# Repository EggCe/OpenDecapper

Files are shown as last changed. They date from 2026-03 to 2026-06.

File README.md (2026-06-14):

# OpenDecapper




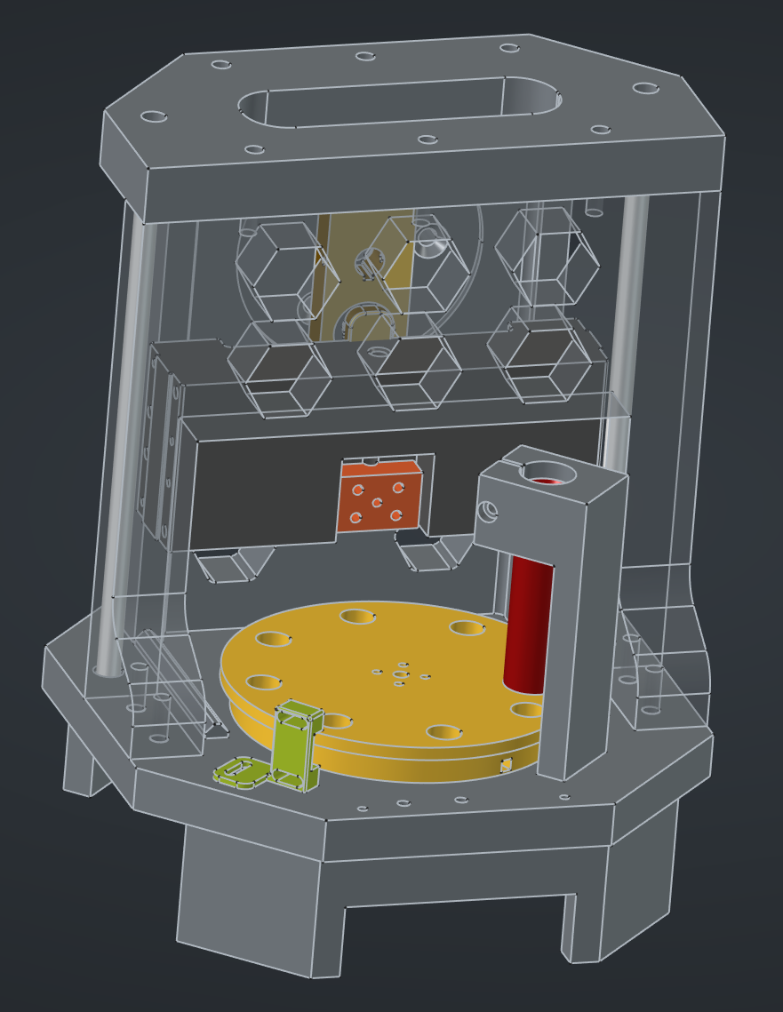
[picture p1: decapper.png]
OpenDecapper Machine


**OpenDecapper** is an open-source, automated hardware solution for decapping fired brass. This project aims to provide a reliable, high-speed alternative to manual decapping by leveraging 3D-printed mechanics and Arduino-based control.

This is a DIY project for educational purposes. Users are responsible for ensuring compliance with local laws and intellectual property.
---

## 📂 Repository Structure

* **/code**: Source code (`.ino`) for the microcontroller. Handles motor control, cycle timing, and sensor feedback.
* **/stl**: STL files for all structural and functional components.

---

## 🛠 Features

* **Automated Cycling:** Continuous feeding and de-priming.
* **Open Hardware:** Fully customizable to fit different bench setups.
* **Adjustable Speed:** Code-based control for different brass conditions.
* **Modular Toolheads:** Quick-swap heads for different calibers.

[Video](https://youtube.com/shorts/UAMVNMfc45k?feature=share)

---

## 🖨️ Print Instructions

For maximum durability and mechanical precision, use the following settings:

- **Baseplate / Frame / Motor-Mount / Decapping-Frame:**

| Setting | Value |
| :--- | :--- |
| **Material** | PETG |
| **Infill** | 40% adaptive cubic |
| **Walls** | 8 |
| **Top Layers** | 7 |
| **Bottom Layers** | 7 |

- **Pleuel/Excenter:**

| Setting | Value |
| :--- | :--- |
| **Material** | PLA |
| **Infill** | 70% Gyroid |
| **Walls** | 8 |
| **Top Layers** | 7 |
| **Bottom Layers** | 7 |

- **Everything Else**

| Setting | Value |
| :--- | :--- |
| **Material** | PLA or PETG |
| **Infill** | 20% Gyroid |
| **Walls** | 3 |
| **Top Layers** | 3 |
| **Bottom Layers** | 3 |

---

## 🚀 Getting Started

### 1. Hardware Requirements
* **Electronics:** Arduino (Nano/Uno), NEMA 17 Stepper Motor, Stepper Driver (TMC2209 or TMC2208).
* **Tools:** 3D Printer (PETG recommended), M3/M5 Bolt kit, 8mm Linear Rails.

### 2. Software Setup
1.  Clone this repository:
    ```bash
    git clone [https://github.com/EggCe/OpenDecapper.git](https://github.com/EggCe/OpenDecapper.git)
    ```
2.  Open `/code/sketch/sketch.ino` in the Arduino IDE.
3.  Install necessary libraries (e.g., `AccelStepper`).
4.  Upload to your board.

---

## 📅 Upcoming Milestones

- [ ] **Comprehensive BOM:** Detailed list of all off-the-shelf parts and fasteners.
- [ ] **Assembly Manual:** Step-by-step instructions with wiring diagrams.
- [ ] **Calibration Guide:** Tips for timing the stroke and sensor alignment.

---

## 🤝 Contributing

Contributions are what make the open-source community such an amazing place to learn, inspire, and create.

---

## ⚖️ License

This project is licensed under the **Creative Commons Attribution-NonCommercial 4.0 International (CC BY-NC 4.0)**. 

**Summary:** You are free to share and adapt this material for non-commercial purposes only. If you remix or build upon this work, you must give appropriate credit. Commercial use of these designs or code is prohibited without explicit permission.

---

**⚠️ SAFETY WARNING:** — READ BEFORE BUILDING OR OPERATING

This machine will crush fingers and hands without breaking a sweat. It is a motorized press driven by a DC motor with significant torque. It does not know or care if something is in the way.

* NEVER run this machine unattended.
* NEVER allow children near the machine, whether it is running or not.
* Keep your hands and fingers away from the machine at ALL times when it is powered on.
* Treat it like any industrial press — it can and will cause serious injury if misused.

LIABILITY DISCLAIMER: This project is provided as-is with absolutely no warranty of any kind. The author(s) accept no responsibility or liability for any injury, damage, or loss resulting from building, modifying, or operating this machine. You build and use it entirely at your own risk.

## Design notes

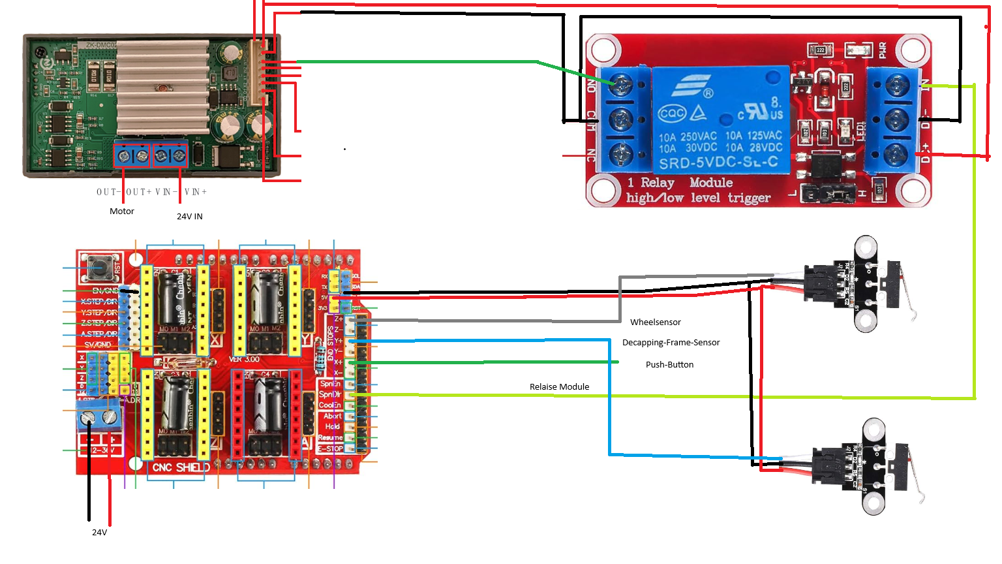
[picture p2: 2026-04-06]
electronics.png

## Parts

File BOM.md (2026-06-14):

# Bill of Materials (BOM) - Project OpenDecapper

### Electronics
| Item | Description | Quantity | Link |
| :--- | :--- | :--- | :---: |
| **Power Supply** | 24V 3A DC Power Supply | 1 | https://de.aliexpress.com/item/33051556213.html |
| **DC Motor** | 24V DC Motor (220 RPM) | 1 | https://de.aliexpress.com/item/1005009774429443.html |
| **DC Motor Controller** | ZK-DMC02 Motor Controller | 1 | https://www.amazon.de/dp/B0GKXSY5CK |
| **Microcontroller** | Arduino Uno R3 | 1 | https://de.aliexpress.com/item/1005007040646073.html |
| **Expansion Board** | CNC Shield V3 | 1 | https://de.aliexpress.com/item/1005007040646073.html |
| **Stepper Driver** | TMC2209 or TMC2208 Stepper Driver | 1 | https://de.aliexpress.com/item/1005006323811276.html |
| **Stepper Motor** | NEMA 17 (1.5A) | 1 | https://de.aliexpress.com/item/1005008383555860.html |
| **Limit Switche** | Mechanical Endstop Limit Switch | 1 | https://de.aliexpress.com/item/32816845922.html |
| **IR Limit Switche** | Infrared Limit Switch | 1 | https://de.aliexpress.com/item/1005006947924085.html |
| **Push-Button** | 12mm Momentary Switch | 1 | https://de.aliexpress.com/item/4000266966662.html |
| **Relais** | Single Channel Relais Modul 5V | 1 | https://de.aliexpress.com/item/1005005319972049.html |

### Mechanical & Motion
| Item | Description | Quantity | Link |
| :--- | :--- | :--- | :---: |
| **Coupling** | 5mm ID Flange Shaft Coupling | 1 | https://de.aliexpress.com/item/1005011579618575.html |
| **Linear Rods** | 8mm Diameter, 215 mm Length | 2 | https://de.aliexpress.com/item/1005009454387776.html | 
| **Linear Bearings** | SC8UU (Gleitlager) | 4 | https://de.aliexpress.com/item/4000861690916.html |
| **Radial Bearing** | 6801 Bearing 12mm ID, 21mm OD| 2 | https://de.aliexpress.com/item/1005006035063081.html |
| **Decapping Pin** | Lee Small Pistol Decapping Pin | 1 |
| **Dillon Index Ball** | Dillon 13891_375 INDEX_BALL (or any 12mm Ball) | 1 |
| **Dillon Index Ball Spring** | Dillon 13997_INDEX BALL SPRING (or any spring fitting) | 1 |

### Hardware (Screws)
| Type | Size | Quantity |
| :--- | :--- | :---: |
| **M6 Bolt** | M6 * 25mm | 14 |
| **M5 Countersunk Bolt** | M6 * 20mm | 3 |
| **M3 Bolt** | M3 * 12mm | 12 |
| **M3 Bolt** | M3 * 8mm | 12 |
| **M3 Bolt** | M3 * 25mm | 30 |
| **M3 Bolt** | M3 * 30mm | 20 |

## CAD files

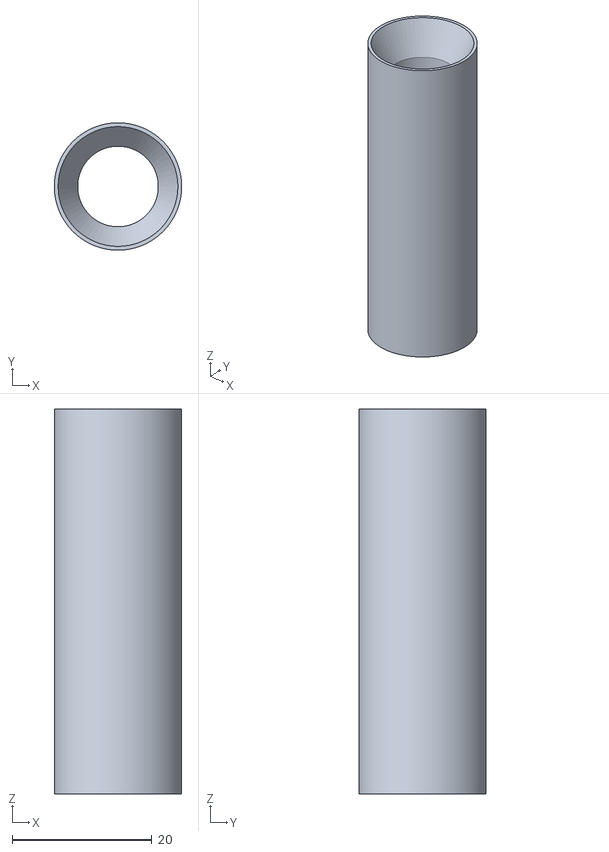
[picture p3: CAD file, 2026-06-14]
stl/caliberConversion/feed-tube-357.stl
18.2 x 18.2 x 55.0

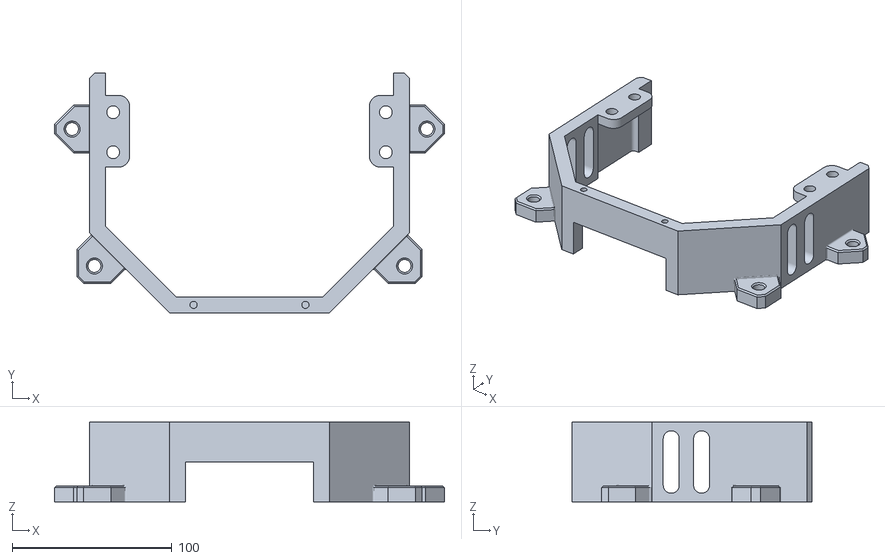
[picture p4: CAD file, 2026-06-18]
stl/FeetExtended-Körper.stl
244.0 x 150.0 x 50.0

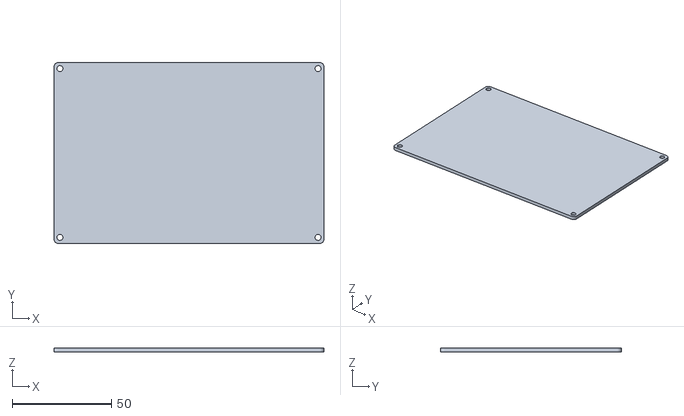
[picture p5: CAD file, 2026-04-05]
stl/pcb/electronics-lid.stl
136.0 x 91.0 x 2.00

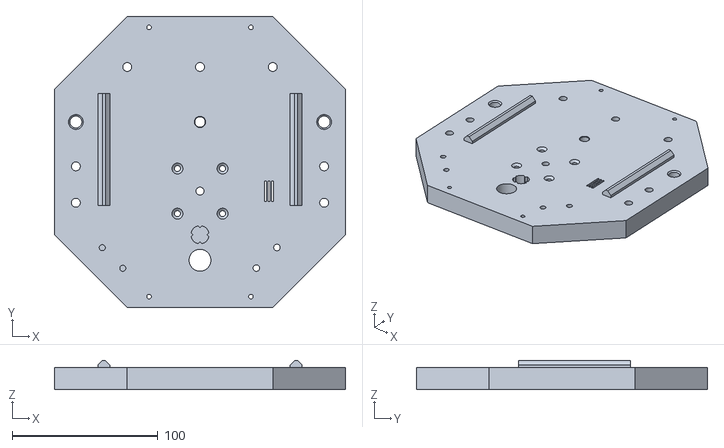
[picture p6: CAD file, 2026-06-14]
stl/Baseplate - Reverse-Körper.stl
200.0 x 200.0 x 20.0

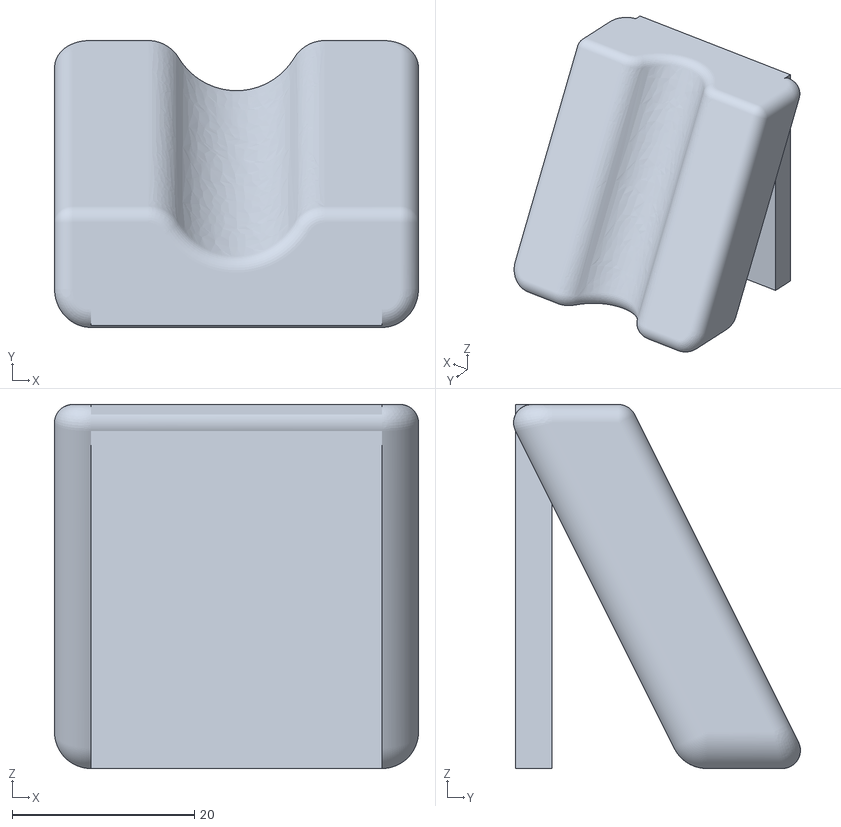
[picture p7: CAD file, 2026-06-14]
stl/caliberConversion/case-guide-Körper.stl
40.0 x 31.5 x 40.0

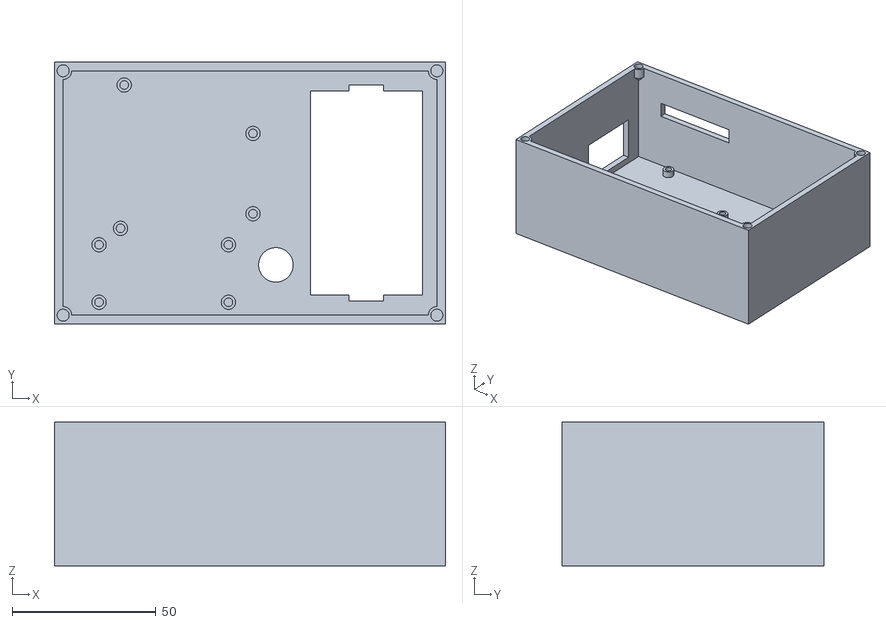
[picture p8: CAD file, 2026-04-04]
stl/pcb/electronic-case.stl
136.0 x 91.0 x 50.0

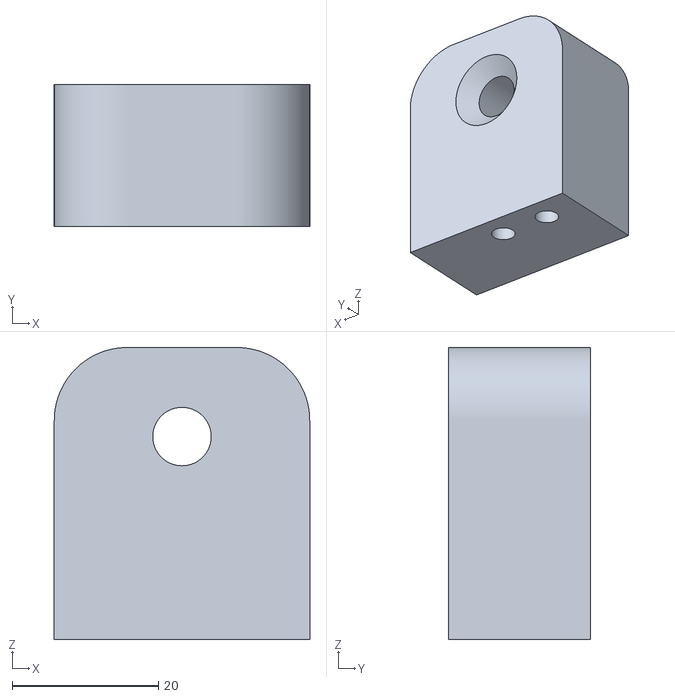
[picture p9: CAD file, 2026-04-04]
stl/caliberConversion/scraper-9mm.stl
35.0 x 19.5 x 40.0

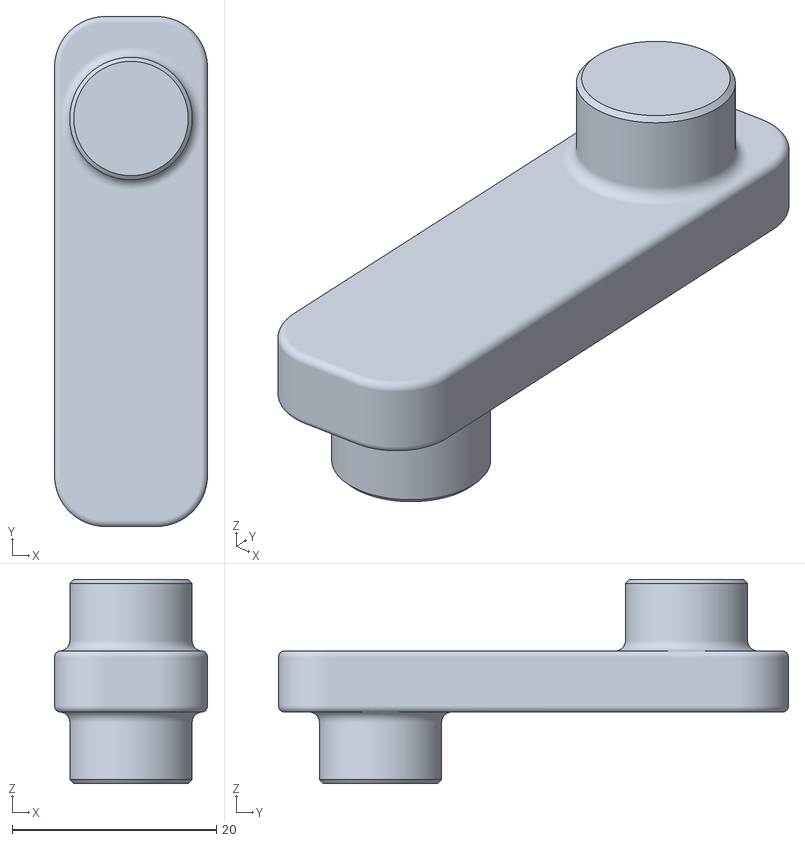
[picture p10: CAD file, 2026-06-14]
stl/pleuel.stl
15.0 x 50.0 x 20.0

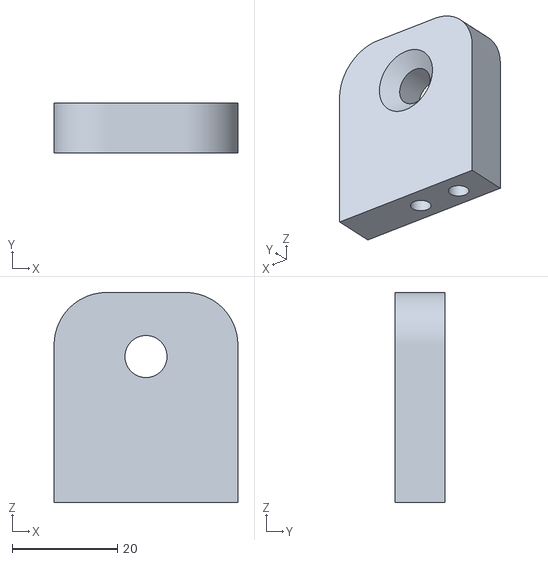
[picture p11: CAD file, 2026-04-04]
stl/caliberConversion/scraper-38spec.stl
35.0 x 9.50 x 40.0

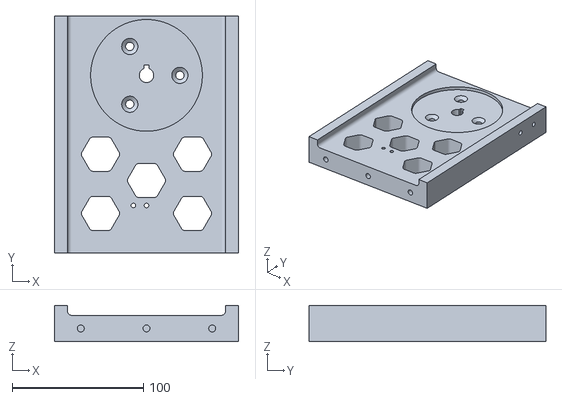
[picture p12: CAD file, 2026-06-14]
stl/motor-mount-Körper.stl
140.0 x 180.0 x 27.5

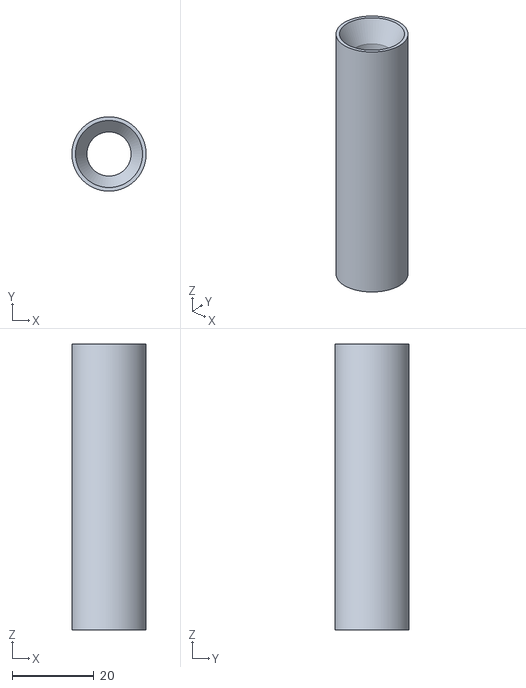
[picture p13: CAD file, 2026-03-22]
stl/caliberConversion/feed-tube-9mm.stl
18.2 x 18.2 x 70.0

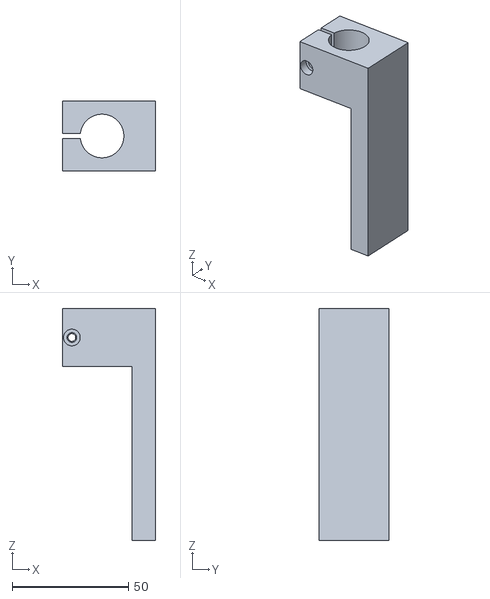
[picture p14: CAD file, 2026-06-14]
stl/tubeholder-Körper.stl
40.0 x 30.0 x 100.0

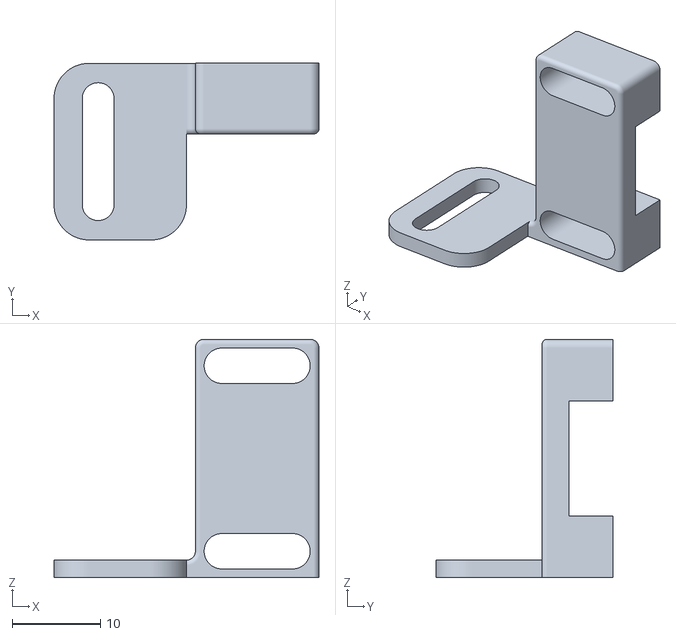
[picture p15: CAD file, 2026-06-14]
stl/Sensor-mount-ir-Körper.stl
30.0 x 20.0 x 27.0

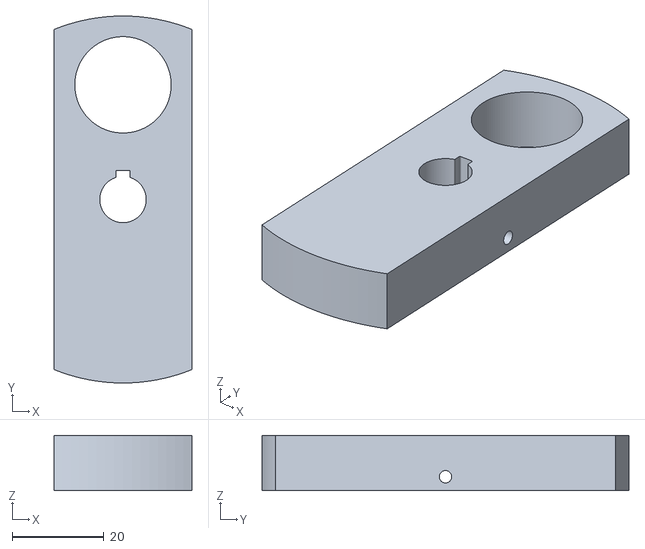
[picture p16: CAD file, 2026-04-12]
stl/exzenter.stl
30.0 x 80.0 x 12.0

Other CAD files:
stl/decapping-frame-gross.stl
stl/frame.stl
stl/Feet.stl
stl/pinClamp.stl
stl/TopLid.stl

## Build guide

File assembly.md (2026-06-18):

# 📖 OpenDecapper Assembly Manual

Follow these steps to assemble your OpenDecapper machine. Ensure all 3D-printed parts are cleaned of supports and holes are cleared before beginning.

---

## 🛠 Phase 1: Base Construction
**Parts Required:** Baseplate, Motor-Mount, Frame, Tube-Holder, TopLid, 2x Feet, M3 Heat Inserts, M6 Screws.

1.  **Prepare the Feet:** Press **M3 heat-set inserts** into the designated holes in the two **Feet**. Mount the feet to the **Baseplate** using M3 screws.
2.  **Stabilizer:** Align the **Stabi** component with the **Baseplate** and secure it firmly using **M6 screws**.
3.  **Tube Holder:** Press **M3 heat-set inserts** into the **Tube-Holder** and mount it to the **Baseplate**.

---

## ⚙️ Phase 2: Decapping Mechanism
**Parts Required:** Decapping-frame, ExcenterBig, PleuelBig, 2x Radial Bearings, 4x Linear Bearings (SC8UU), 2x 8mm Rods (220mm).

1.  **Bearing Press:** Install the **Radial Bearings** into the **Pleuel** and the **Excenter**.
2.  **Motor Prep:** Mount the DC Motor to the **Motor-Mount** using **3x M5 screws**. 
3.  **Excenter Fit:** Slide the **Excenter** onto the motor shaft. Ensure the shaft is seated flat against the excenter's internal profile. Fix Excenter with screws to the shaft of the motor.
4.  **Frame Preparation:** Install the **4 Linear Bearings** onto the sides of the **Decapping-frame**. 
    * *Note:* Use M3 screws directly into the plastic. If extra strength is needed, use M3 heat-set inserts in the frame.
5.  **Linear Assembly:** Insert the two **8mm Linear Rods** into the **Baseplate**. Slide the assembled **Decapping-frame** onto the rods.
6.  **Final Linkage:** Mount the **Motor-Mount** assembly onto the **Baseplate**. While positioning it, ensure the bearing from the **Pleuel** sits correctly into the **Decapping-frame**.

---

## 🔄 Phase 3: Brass Feed System
**Parts Required:** Caliber Wheel, Caliber Tube, CaliberScraper, NEMA 17 Stepper, 5mm Flange Coupling.

1.  **Stepper Install:** Mount the **NEMA 17 Motor** to the **Baseplate**.
2.  **Index Install:** Place Dillon **Index Spring** and **Index Ball** into indexing hole.
3.  **Coupling:** Mount the **5mm Flange Coupling** onto the **Caliber Wheel**.
4.  **Wheel Mounting:** Place the wheel onto the NEMA 17 shaft. You can tighten the coupling set-screws from the side of the assembly.

---

## 🛑 Phase 4: Sensors & Calibration
**Parts Required:** 2x Mechanical Limit Switches.

1.  **Feed Alignment:** Mount the  **IR Limit Switch** to the **Baseplate**. 
    * **Calibration:** Align it so the hole in the wheel perfectly matches the decapping hole in the baseplate when the switch is activated. Accuracy here is vital for reliability.
2.  **Cycle Indexing:** Mount the second **Limit Switch** to the **Motor-Mount**.
3.  **Home Position:** Position this switch so it activates at the **highest point (Top Dead Center)** of the decapping frame's movement.

---

### ✅ Assembly Complete
Double-check all fasteners and ensure the mechanisms move smoothly by hand before connecting the 24V power supply.

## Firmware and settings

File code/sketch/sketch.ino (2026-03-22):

#include <Wire.h>
#define WHEEL_SENSOR 11 
#define DECAPPING_SENSOR 10 
#define DECAPPING_MOTOR 13 
#define TURNER_DIRPIN 5 
#define TURNER_STEPPIN 2 
#define TURNER_ENABLE 8 
#define START_STOP_BUTTON 9
#define TURN_MOTOR_SPEED 1200 

bool systemRunning = false;
bool lastButtonState = HIGH;

void setup() {
  Serial.begin(9600);
  pinMode(WHEEL_SENSOR, INPUT_PULLUP);
  pinMode(DECAPPING_SENSOR, INPUT_PULLUP);
  pinMode(START_STOP_BUTTON, INPUT_PULLUP);
  pinMode(DECAPPING_MOTOR, OUTPUT);
   
  pinMode(TURNER_DIRPIN, OUTPUT);
  pinMode(TURNER_STEPPIN, OUTPUT);
  pinMode(TURNER_ENABLE, OUTPUT);

  digitalWrite(DECAPPING_MOTOR, LOW); 
  digitalWrite(TURNER_ENABLE, LOW); // stepper
  digitalWrite(TURNER_DIRPIN, LOW); // Set direction
  
  // --- INITIAL INDEXING PHASE ---
  indexHardware();
  Serial.println("System Ready. Press Button to Start.");
}

void loop() {
  checkButton();
  // 1. Rotate Wheel until sensor hit
  if (systemRunning) {
  rotateWheelToSensor();
  // 2. Run Decapper until sensor hit
  if(!systemRunning) return;
  runDecapperToSensor();
  // Small pause for stability
  delay(500); 
  }else {
    digitalWrite(TURNER_ENABLE, LOW); // Disable Stepper when stopped
    digitalWrite(DECAPPING_MOTOR, LOW); // Ensure decapper is off
  }
}

void checkButton() {
  bool currentButtonState = digitalRead(START_STOP_BUTTON);
  
  // Detect button press (Transition from HIGH to LOW)
  if (lastButtonState == HIGH && currentButtonState == LOW) {
    systemRunning = !systemRunning; // Toggle state
    Serial.print("System Running: ");
    Serial.println(systemRunning ? "ON" : "OFF");
    delay(200); // Simple debounce
  }
  lastButtonState = currentButtonState;
}

// Moves the stepper until the limit switch is triggered
void rotateWheelToSensor() {
  // Move off the sensor first if it's already triggered
while(digitalRead(WHEEL_SENSOR) == HIGH) {
    stepMotor();
  }
  // Move until it hits the sensor
  while(digitalRead(WHEEL_SENSOR) == LOW) {
    stepMotor();
  }
}

// Runs DC motor until the decapping limit switch is triggered
void runDecapperToSensor() {
  if(digitalRead(WHEEL_SENSOR) == HIGH){
  digitalWrite(DECAPPING_MOTOR, HIGH);
  delay(800);
  while(digitalRead(DECAPPING_SENSOR) == LOW) {
    digitalWrite(DECAPPING_MOTOR, HIGH);
  }
  digitalWrite(DECAPPING_MOTOR, LOW);
  }
}

void stepMotor() {
  digitalWrite(TURNER_STEPPIN, HIGH);
  delayMicroseconds(10); 
  digitalWrite(TURNER_STEPPIN, LOW);
  delayMicroseconds(TURN_MOTOR_SPEED);
}

void indexHardware() {
  // Logic to home both components on startup
  rotateWheelToSensor();
  delay(2000);
  runDecapperToSensor();
}

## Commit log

2026-03-22 print instructions
2026-03-22 9mm wheel
    [wheel-9mm.stl]
2026-06-14 updated parts
    [Baseplate - Reverse-Körper.stl, Baseplate.stl, Sensor-mount-ir-Körper.stl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]
2026-06-14 print settings
2026-06-18 extended screw down Feet
    [FeetExtended-Körper.stl]
2026-06-18 update foot
    [FeetExtended-Körper.stl]

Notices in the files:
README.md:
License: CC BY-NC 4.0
